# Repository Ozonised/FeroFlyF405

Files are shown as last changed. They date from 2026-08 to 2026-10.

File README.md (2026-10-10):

# FeroFlyF405
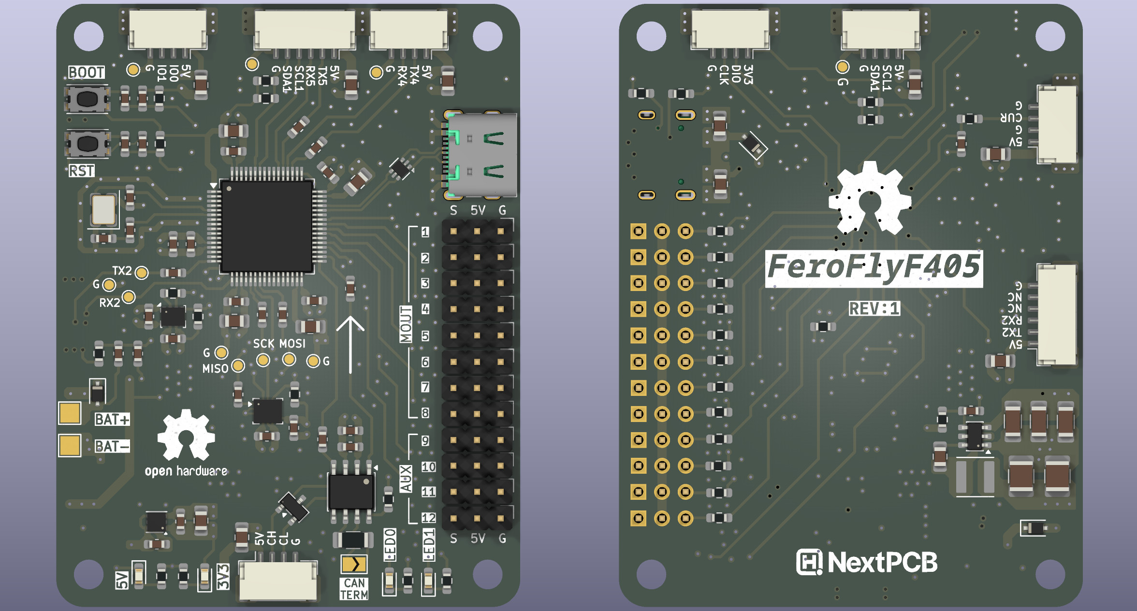
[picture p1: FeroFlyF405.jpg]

FeroFlyF405 is an opensource flight controller based on STM32F405 and runs the open source flight controller firmware, [INAV](https://github.com/iNavFlight/inav).

FeroFlyF405 is designed to be an open hardware platform that enthusiasts and developers can study, modify, build, and use in their own projects.

For those interested in the design process, watch the [YouTube](https://youtu.be/mWAzVRxgooY) video.

## Features

* **Microcontroller:** STM32F405
* **IMU:** LSM6DSL 6-axis accelerometer and gyroscope
* **Barometer:** DPS368
* **Firmware:** INAV
* **Motor outputs:** 12 timer-based output channels
* **CAN bus:** For compatible peripherals
* **I2C:** External sensor and peripheral connectivity
* **UARTs:** 3 serial ports
* **PINIO:** 2 programmable GPIO outputs
* **Current sensing:** Dedicated input for an external current sensor

## Sponsor

A special thanks to **[NextPCB](https://www.nextpcb.com/?code=ozonised)** for sponsoring the FeroFlyF405 project and supporting the development of this open-source flight controller.

Their support helped bring the custom PCB design from the screen to the physical board.

Thank you, NextPCB, for supporting open-source hardware development!

Get high quality PCBs for your project at an affordable rate from **[NextPCB](https://www.nextpcb.com/)**.

## Connectivity

| Interface | Quantity | Purpose |
| --- | ---: | --- |
| Motor outputs  | 12 | ESCs and other compatible timer-based outputs |
| CAN bus | 1 | Compatible CAN peripherals |
| I2C | 1 | External sensors and peripherals |
| UART | 3 | Receivers, GPS, telemetry, and other serial devices |
| PINIO | 2 | User-configurable GPIO outputs |
| Current sensor | 1 | External current-sensing module |

> **Note:** Motor output capabilities depend on timer allocation, DMA availability, and firmware configuration. Not all outputs necessarily support every ESC protocol.

## Connectors and Pinout

FeroFlyF405 follows the **Pixhawk connector and pinout standard** for its applicable peripheral interfaces and uses **JST-GH series connectors**.

The PINIO and current-sensor connectors are exceptions to this convention.

## Firmware

FeroFlyF405 runs [INAV](https://github.com/iNavFlight/inav), an open-source flight control firmware for multirotor, fixed-wing, and other UAV platforms.

FeroFlyF405 uses a board-specific INAV target to configure its MCU pins, sensors, timers, communication interfaces, and other hardware resources.

Useful links:
* [FeroFlyF405 Target & Binary](https://github.com/Ozonised/FeroFlyF405-INAV-files)
* [INAV source code](https://github.com/iNavFlight/inav)
* [INAV documentation](https://inavflight.github.io/)

## 3D-Printed Enclosure

The FeroFlyF405 enclosure consists of three 3D-printable parts:

* **Enclosure Top** (`FeroFlyF405 Enclosure-Top.stl`) — Upper section of the enclosure.
* **Enclosure Bottom** (`FeroFlyF405 Enclosure-Bottom.stl`) — Lower section of the enclosure.
* **LED Cap** (`FeroFlyF405 Enclosure-Led Cap.stl`) — Cover for the status and power LEDs, designed to be printed using translucent filament to allow the LED light to pass through.

### Printing Recommendations

* **Top and Bottom:** PETG filament is recommended for durability and heat resistance.
* **LED Cap:** Use translucent filament for better LED visibility.
* **Fasteners:** The enclosure uses M3 screws and threaded inserts.

The STL files are provided so you can print and assemble the enclosure yourself.

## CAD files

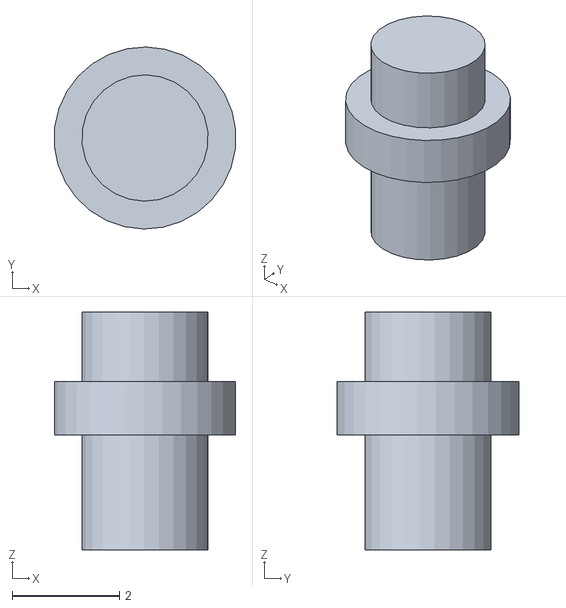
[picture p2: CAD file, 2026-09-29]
Enclosure/FeroFlyF405 Enclosure-Led Cap.stl
3.39 x 3.40 x 4.45

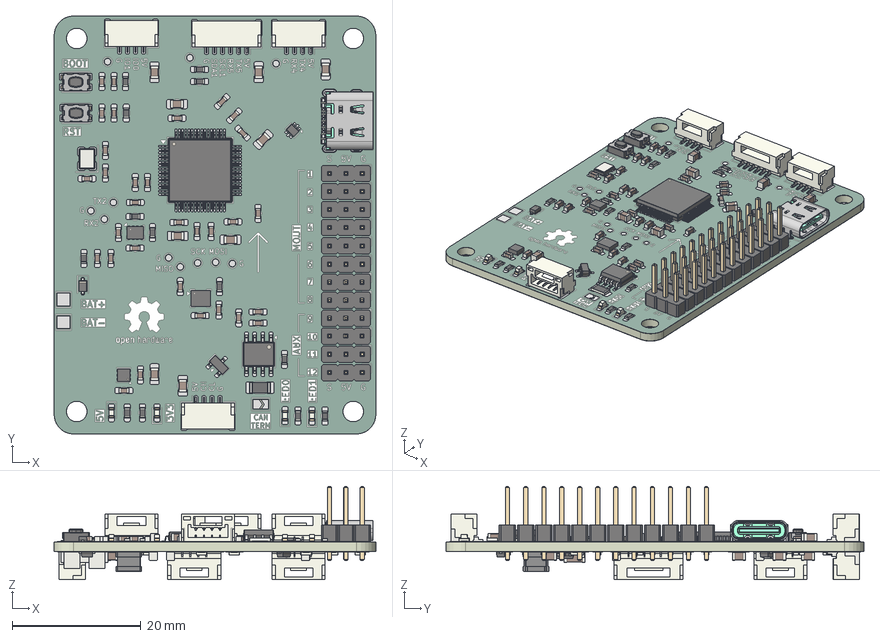
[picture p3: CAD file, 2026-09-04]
FeroFlyF405.step
50.0 x 65.0 x 14.5 mm
LED_0603_1608Metric x 4
R_0603_1608Metric x 34
SOT_666
Bosch_LGA_8_2x25mm_P065mm_ClockwisePinNumbering
C_0603_1608Metric x 33
PinHeader_1x03_P254mm_Vertical x 12
JST_SM04B_GHS_TB x 6
_X2_4E006B21_X0_MOLDING_-261340
WSON_6_1EP_2x2mm_P065mm_EP1x16mm
SOIC-8_3.9x4.9mm_P1.27mm
C_0805_2012Metric x 15
LQFP-64_10x10mm_P0.5mm
SW_Push_1P1T_NO_CK_KMR2 x 2
JST_SM06B_GHS_TB x 2
LGA_14_3x25mm_P05mm_LayoutBorder3x4y
SOT-23
D_SOD_323F x 3
Crystal_SMD_3225-4Pin_3.2x2.5mm
R_1206_3216Metric
C_1206_3216Metric x 3
TSOT-23-6
C_1210_3225Metric x 2
ASPI-4030S
FeroFlyF405_pad
FeroFlyF405_silkscreen x 2
FeroFlyF405_soldermask x 2
FeroFlyF405_PCB

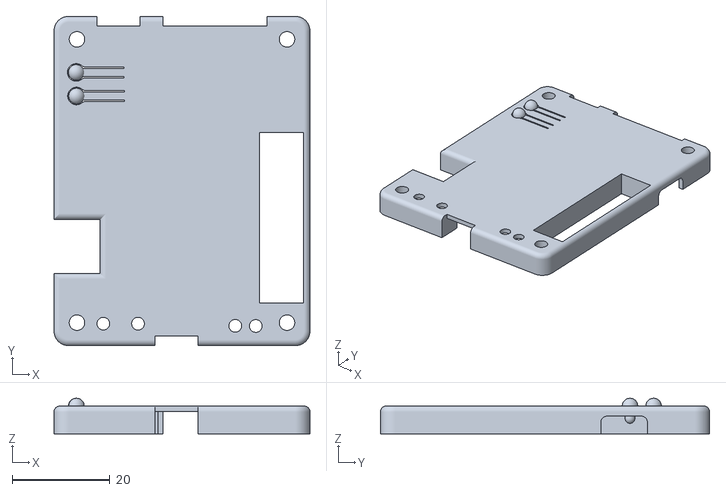
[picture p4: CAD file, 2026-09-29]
Enclosure/FeroFlyF405 Enclosure-Top.stl
52.4 x 67.4 x 7.28

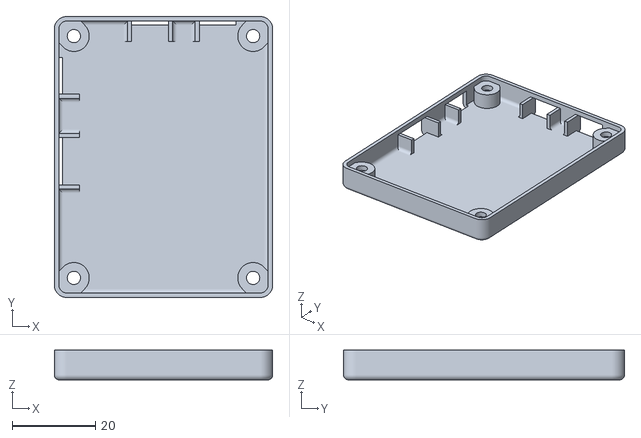
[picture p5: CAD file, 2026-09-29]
Enclosure/FeroFlyF405 Enclosure-Bottom.stl
52.4 x 67.4 x 7.14

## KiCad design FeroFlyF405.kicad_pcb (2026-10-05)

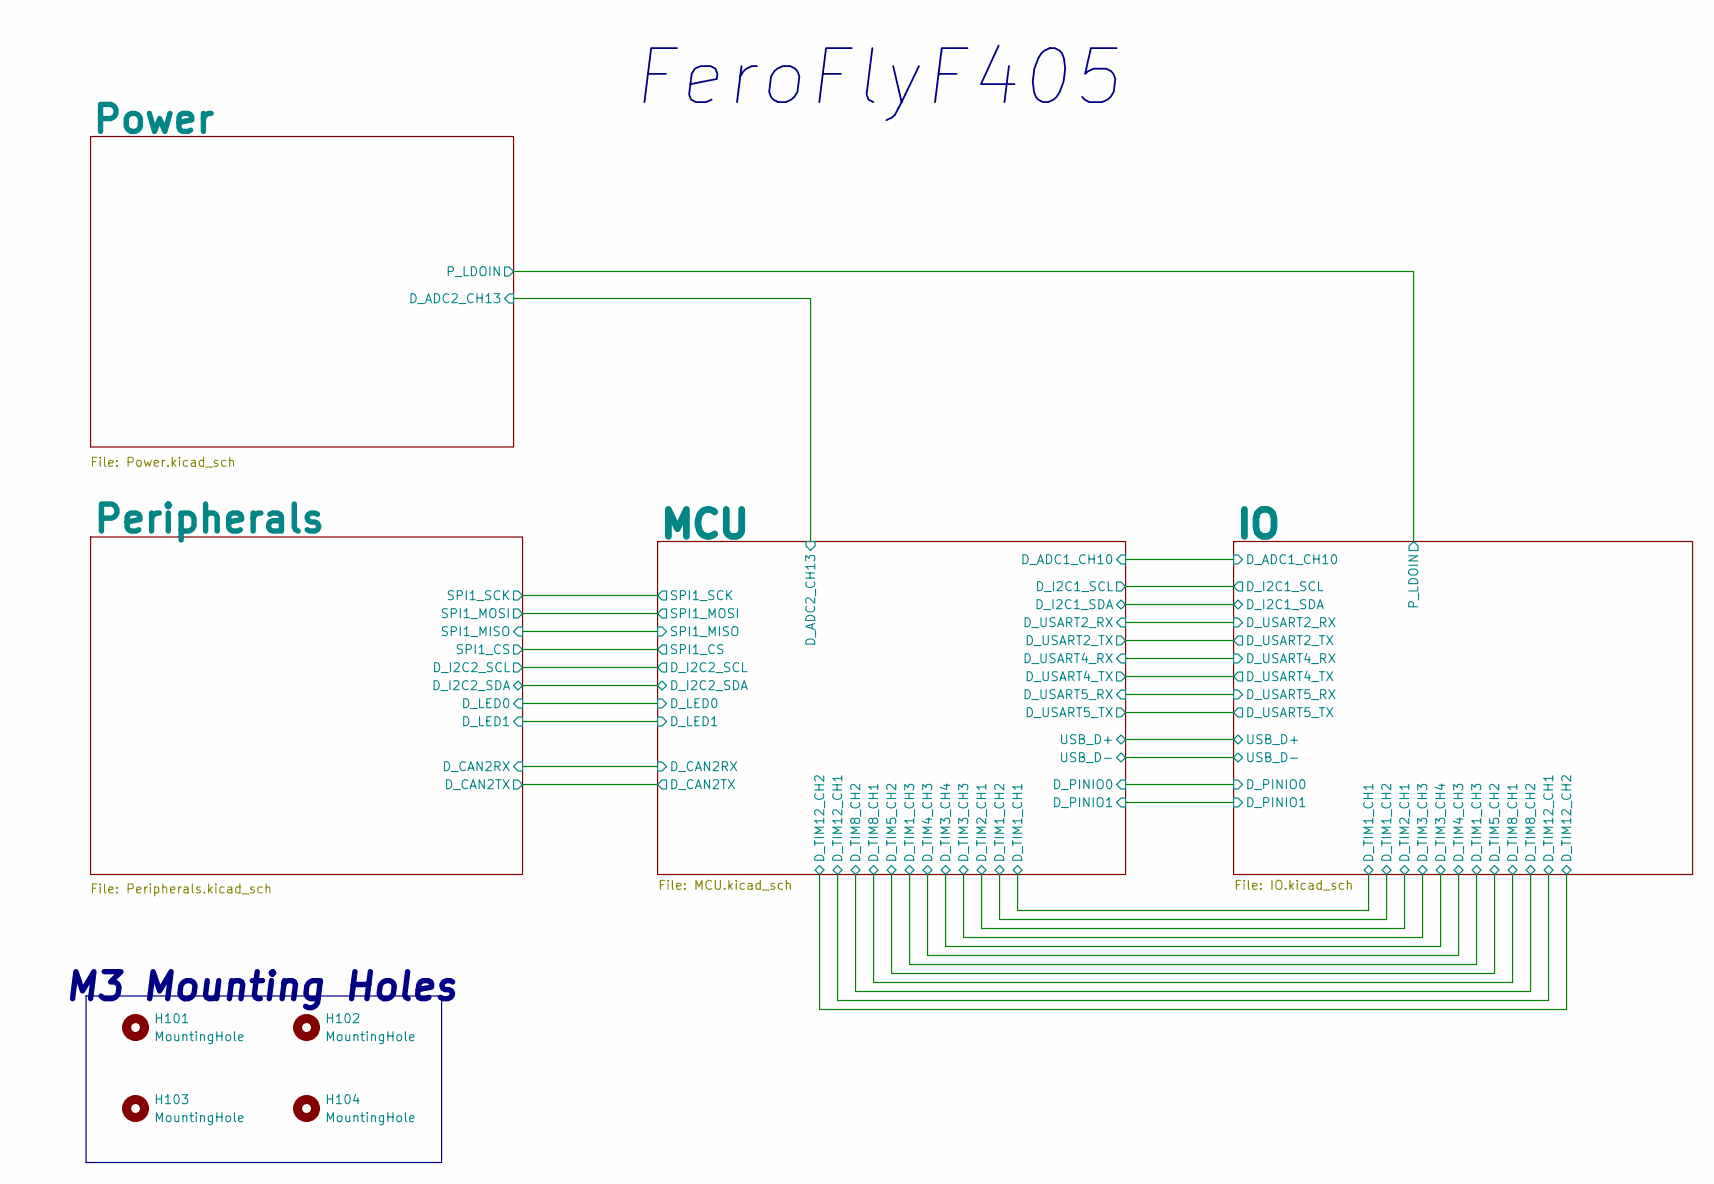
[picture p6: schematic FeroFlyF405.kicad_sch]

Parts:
H101, H102, H103, H104: MountingHole; MountingHole_3.2mm_M3

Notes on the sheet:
M3 Mounting Holes
FeroFlyF405

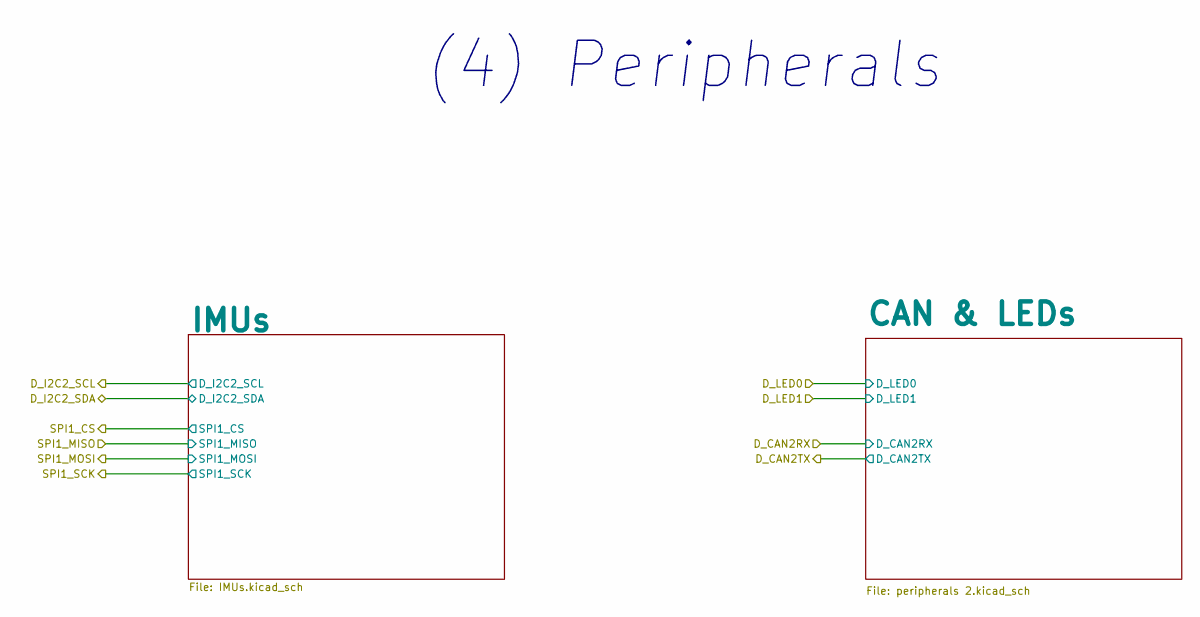
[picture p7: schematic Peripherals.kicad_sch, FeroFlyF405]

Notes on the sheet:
(4) Peripherals

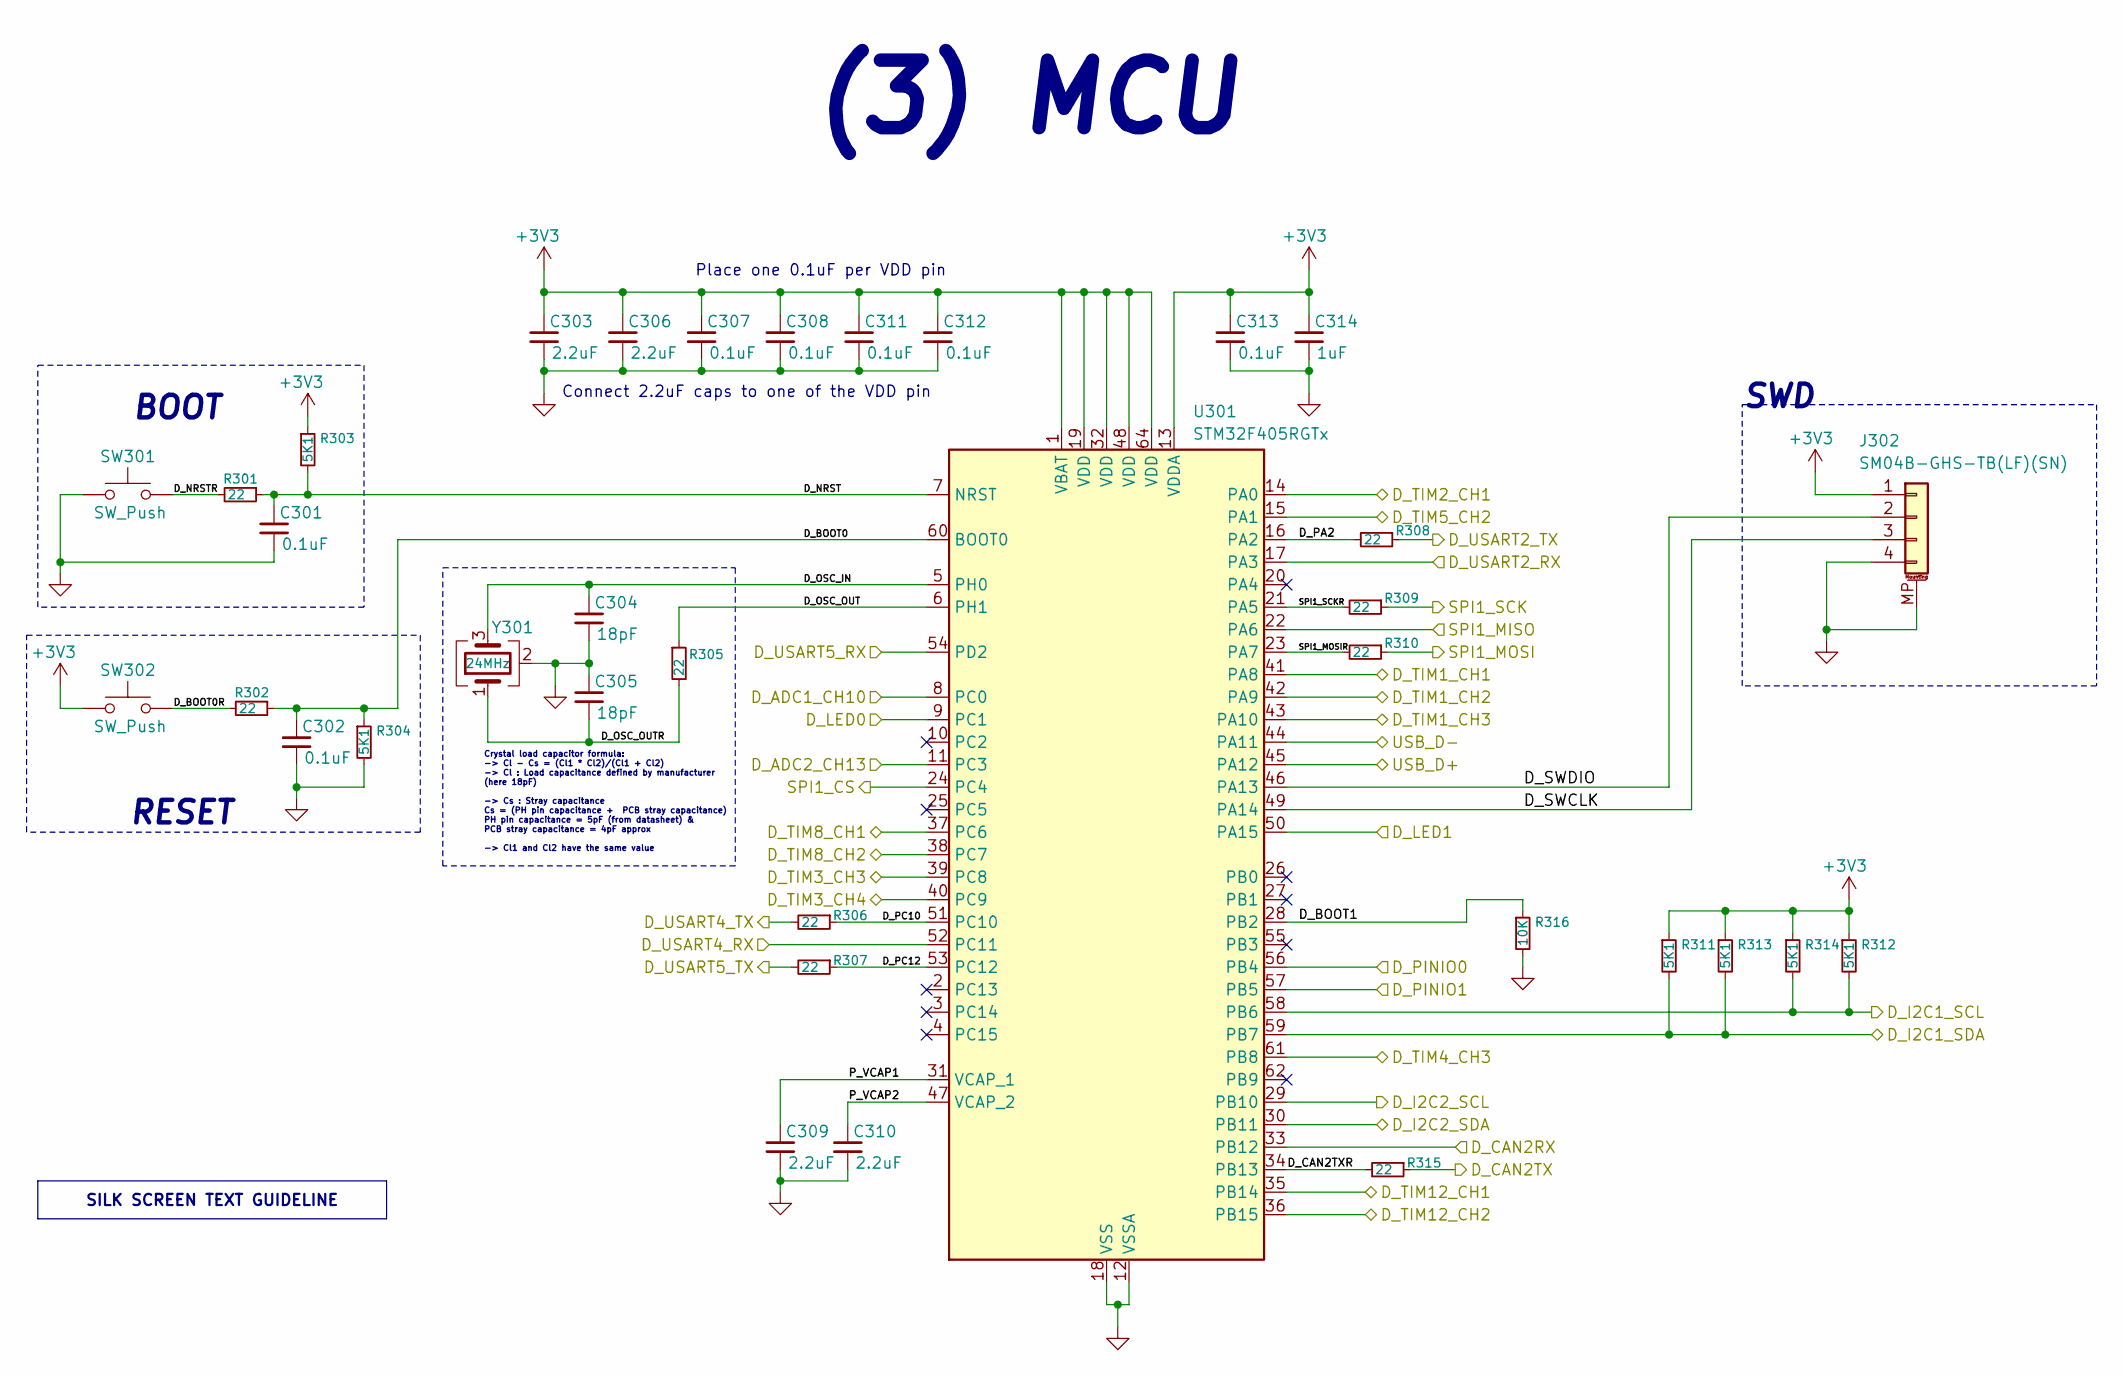
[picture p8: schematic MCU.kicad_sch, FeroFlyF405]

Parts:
C301, C302, C307, C308, C311, C312, C313: 0.1uF; C_0603_1608Metric_Pad1.08x0.95mm_HandSolder; MPN C1608X5R1H104K080AA
C303, C306, C309, C310: 2.2uF; C_0805_2012Metric_Pad1.18x1.45mm_HandSolder; MPN GCM21BR71C225KA64L
C304, C305: 18pF; C_0603_1608Metric_Pad1.08x0.95mm_HandSolder; MPN 06035A180JAT4A
C314: 1uF; C_0603_1608Metric_Pad1.08x0.95mm_HandSolder; MPN C1608X7R1V105K080AC
J302: SM04B-GHS-TB(LF)(SN); JST_GH_SM04B-GHS-TB_1x04-1MP_P1.25mm_Horizontal; MPN SM04B-GHS-TB(LF)(SN)
R301, R302, R305, R306, R307, R308, R309, R310, R315: 22; C_0603_1608Metric_Pad1.08x0.95mm_HandSolder; MPN CR0603-FX-22R0ELF
R303, R304, R311, R312, R313, R314: 5K1; R_0603_1608Metric_Pad0.98x0.95mm_HandSolder; MPN CR0603-FX-5101ELF
R316: 10K; R_0603_1608Metric_Pad0.98x0.95mm_HandSolder; MPN CR0603-FX-1002ELF
SW301, SW302: SW_Push; SW_Push_1P1T_NO_CK_KMR2; MPN RKB2SJM250SMTR LFS
U301: STM32F405RGTx; LQFP-64_10x10mm_P0.5mm; MPN STM32F405RGT6
Y301: 24MHz; Crystal_SMD_3225-4Pin_3.2x2.5mm; MPN ABM8-24.000MHZ-D4Y-T

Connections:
+3V3: C303.1, C306.1, C307.1, C308.1, C311.1, C312.1, C313.1, C314.1, J302.1, R303.1, R311.1, R312.1, R313.1, R314.1, SW302.1, U301.1 (VBAT), U301.13 (VDDA), U301.19 (VDD), U301.32 (VDD), U301.48 (VDD), U301.64 (VDD); also elsewhere on the board
/IO/D_ADC1_CH10: U301.8 (PC0); also elsewhere on the board
/IO/D_I2C1_SCL: R312.2, R314.2, U301.58 (PB6); also elsewhere on the board
/IO/D_I2C1_SDA: R311.2, R313.2, U301.59 (PB7); also elsewhere on the board
/IO/D_PINIO0: U301.56 (PB4); also elsewhere on the board
/IO/D_PINIO1: U301.57 (PB5); also elsewhere on the board
/IO/D_TIM1_CH1: U301.41 (PA8); also elsewhere on the board
/IO/D_TIM1_CH2: U301.42 (PA9); also elsewhere on the board
/IO/D_TIM1_CH3: U301.43 (PA10); also elsewhere on the board
/IO/D_TIM2_CH1: U301.14 (PA0); also elsewhere on the board
/IO/D_TIM3_CH3: U301.39 (PC8); also elsewhere on the board
/IO/D_TIM3_CH4: U301.40 (PC9); also elsewhere on the board
/IO/D_TIM4_CH3: U301.61 (PB8); also elsewhere on the board
/IO/D_TIM5_CH2: U301.15 (PA1); also elsewhere on the board
/IO/D_TIM8_CH1: U301.37 (PC6); also elsewhere on the board
/IO/D_TIM8_CH2: U301.38 (PC7); also elsewhere on the board
/IO/D_TIM12_CH1: U301.35 (PB14); also elsewhere on the board
/IO/D_TIM12_CH2: U301.36 (PB15); also elsewhere on the board
/IO/D_USART2_RX: U301.17 (PA3); also elsewhere on the board
/IO/D_USART2_TX: R308.1; also elsewhere on the board
/IO/D_USART4_RX: U301.52 (PC11); also elsewhere on the board
/IO/D_USART4_TX: R306.2; also elsewhere on the board
/IO/D_USART5_RX: U301.54 (PD2); also elsewhere on the board
/IO/D_USART5_TX: R307.2; also elsewhere on the board
/IO/USB_D+: U301.45 (PA12); also elsewhere on the board
/IO/USB_D-: U301.44 (PA11); also elsewhere on the board
/MCU/D_ADC2_CH13: U301.11 (PC3); also elsewhere on the board
/MCU/D_BOOT0: C302.1, R302.1, R304.1, U301.60 (BOOT0)
/MCU/D_BOOT0R: R302.2, SW302.2
/MCU/D_BOOT1: R316.1, U301.28 (PB2)
/MCU/D_CAN2RX: U301.33 (PB12); also elsewhere on the board
/MCU/D_CAN2TX: R315.1; also elsewhere on the board
/MCU/D_CAN2TXR: R315.2, U301.34 (PB13)
/MCU/D_I2C2_SCL: U301.29 (PB10); also elsewhere on the board
/MCU/D_I2C2_SDA: U301.30 (PB11); also elsewhere on the board
/MCU/D_LED0: U301.9 (PC1); also elsewhere on the board
/MCU/D_LED1: U301.50 (PA15); also elsewhere on the board
/MCU/D_NRST: C301.1, R301.1, R303.2, U301.7 (NRST)
/MCU/D_NRSTR: R301.2, SW301.2
/MCU/D_OSC_IN: C304.1, U301.5 (PH0), Y301.3
/MCU/D_OSC_OUT: R305.1, U301.6 (PH1)
/MCU/D_OSC_OUTR: C305.2, R305.2, Y301.1
/MCU/D_PA2: R308.2, U301.16 (PA2)
/MCU/D_PC10: R306.1, U301.51 (PC10)
/MCU/D_PC12: R307.1, U301.53 (PC12)
/MCU/D_SWCLK: J302.3, U301.49 (PA14)
/MCU/D_SWDIO: J302.2, U301.46 (PA13)
/MCU/P_VCAP1: C309.1, U301.31 (VCAP_1)
/MCU/P_VCAP2: C310.1, U301.47 (VCAP_2)
/MCU/SPI1_CS: U301.24 (PC4); also elsewhere on the board
/MCU/SPI1_MISO: U301.22 (PA6); also elsewhere on the board
/MCU/SPI1_MOSI: R310.1; also elsewhere on the board
/MCU/SPI1_MOSIR: R310.2, U301.23 (PA7)
/MCU/SPI1_SCK: R309.1; also elsewhere on the board
/MCU/SPI1_SCKR: R309.2, U301.21 (PA5)
GND: C301.2, C302.2, C303.2, C304.2, C305.1, C306.2, C307.2, C308.2, C309.2, C310.2, C311.2, C312.2, C313.2, C314.2, J302.4, J302.MP (MountPin), R304.2, R316.2, SW301.1, U301.12 (VSSA), U301.18 (VSS), U301.63 (VSS), Y301.2 (G), Y301.4 (G); also elsewhere on the board

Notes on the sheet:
RESET
SWD
Place one 0.1uF per VDD pin
Crystal load capacitor formula: -> Cl - Cs = (Cl1 * Cl2)/(Cl1 + Cl2) -> Cl : Load capacitance defined by manufacturer (here 18pF) -> Cs : Stray capacitance Cs = (PH pin capacitance + PCB stray capacitance) PH pin capacitance = 5pF (from datasheet) & PCB stray capacitance = 4pF approx -> Cl1 and Cl2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
(3) MCU
Connect 2.2uF caps to one of the VDD pin
BOOT
SILK SCREEN TEXT GUIDELINE

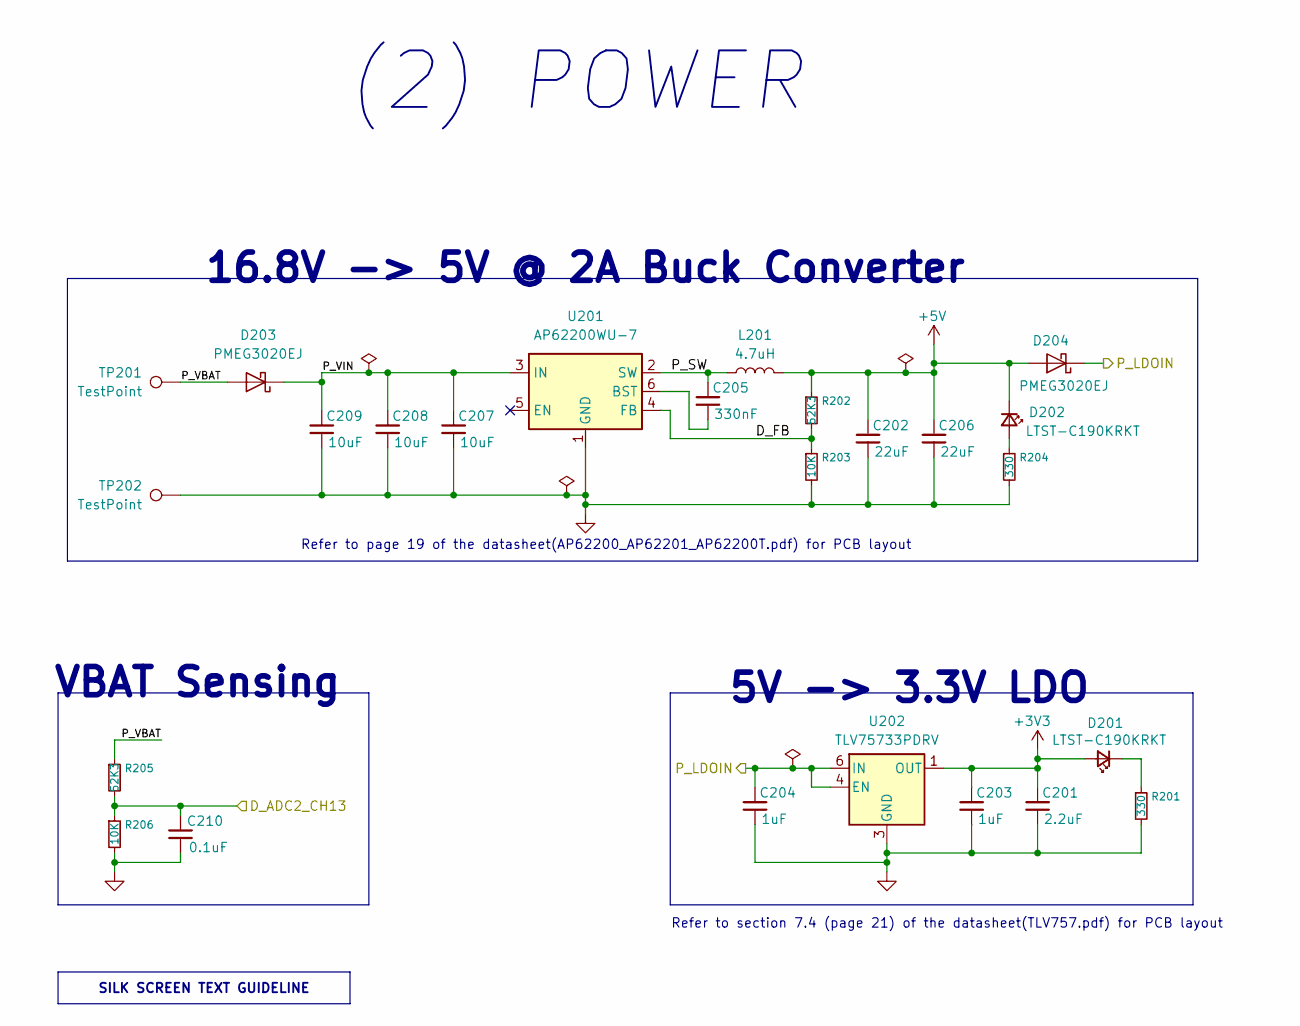
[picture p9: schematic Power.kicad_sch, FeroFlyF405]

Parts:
C201: 2.2uF; C_0805_2012Metric_Pad1.18x1.45mm_HandSolder; MPN GCM21BR71C225KA64L
C202, C206: 22uF; C_1210_3225Metric_Pad1.33x2.70mm_HandSolder; MPN C3225X5R1C226M250AA
C203, C204: 1uF; C_0603_1608Metric_Pad1.08x0.95mm_HandSolder; MPN C1608X7R1V105K080AC
C205: 330nF; C_0805_2012Metric_Pad1.18x1.45mm_HandSolder; MPN CGA4J2X7R1H334K125AA
C207, C208, C209: 10uF; C_1206_3216Metric_Pad1.33x1.80mm_HandSolder; MPN C3216X5R1E106K160AB
C210: 0.1uF; C_0603_1608Metric_Pad1.08x0.95mm_HandSolder; MPN C1608X5R1H104K080AA
D201, D202: LTST-C190KRKT; LED_0603_1608Metric_Pad1.05x0.95mm_HandSolder; MPN LTST-C190KRKT
D203, D204: PMEG3020EJ; D_SOD-323F; MPN PMEG3020EJ,115
L201: 4.7uH; L_Abracon_ASPI-4030S; MPN ASPI-4030S-4R7M-T
R201, R204: 330; R_0603_1608Metric_Pad0.98x0.95mm_HandSolder; MPN CR0603-FX-3300ELF
R202, R205: 52K3; C_0603_1608Metric_Pad1.08x0.95mm_HandSolder; MPN CR0603-FX-5232ELF
R203, R206: 10K; R_0603_1608Metric_Pad0.98x0.95mm_HandSolder; MPN CR0603-FX-1002ELF
TP201, TP202: TestPoint; TestPoint_Pad_2.0x2.0mm
U201: AP62200WU-7; TSOT-23-6; MPN AP62200WU-7
U202: TLV75733PDRV; WSON-6-1EP_2x2mm_P0.65mm_EP1x1.6mm; MPN TLV75733PDRVR

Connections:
+3V3: C201.1, C203.1, D201.2 (A), U202.1 (OUT); also elsewhere on the board
+5V: C202.1, C206.1, D202.1 (K), D204.2 (A), L201.2, R202.1; also elsewhere on the board
/IO/P_LDOIN: C204.1, D204.1 (K), U202.4 (EN), U202.6 (IN); also elsewhere on the board
/MCU/D_ADC2_CH13: C210.1, R205.2, R206.1; also elsewhere on the board
/Power/D_FB: R202.2, R203.1, U201.4 (FB)
/Power/P_SW: C205.1, L201.1, U201.2 (SW)
/Power/P_VBAT: D203.2 (A), R205.1, TP201.1 (1_1)
/Power/P_VIN: C207.1, C208.1, C209.1, D203.1 (K), U201.3 (IN)
GND: C201.2, C202.2, C203.2, C204.2, C206.2, C207.2, C208.2, C209.2, C210.2, R201.2, R203.2, R204.2, R206.2, TP202.1 (1_1), U201.1 (GND), U202.3 (GND), U202.7 (GND); also elsewhere on the board
unnamed: D201.1 (K), R201.1
unnamed: D202.2 (A), R204.1
unnamed: C205.2, U201.6 (BST)

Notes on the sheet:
Refer to page 19 of the datasheet(AP62200_AP62201_AP62200T.pdf) for PCB layout
5V -> 3.3V LDO
16.8V -> 5V @ 2A Buck Converter
(2) POWER
Refer to section 7.4 (page 21) of the datasheet(TLV757.pdf) for PCB layout
VBAT Sensing
SILK SCREEN TEXT GUIDELINE

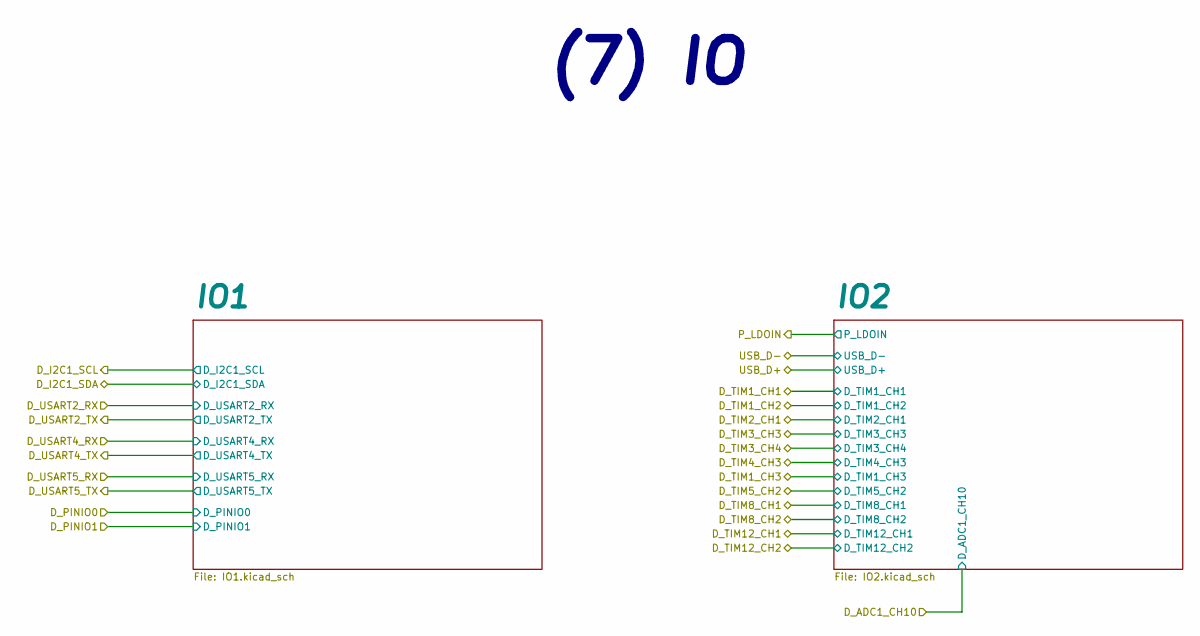
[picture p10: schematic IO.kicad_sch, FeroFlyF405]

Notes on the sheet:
(7) IO

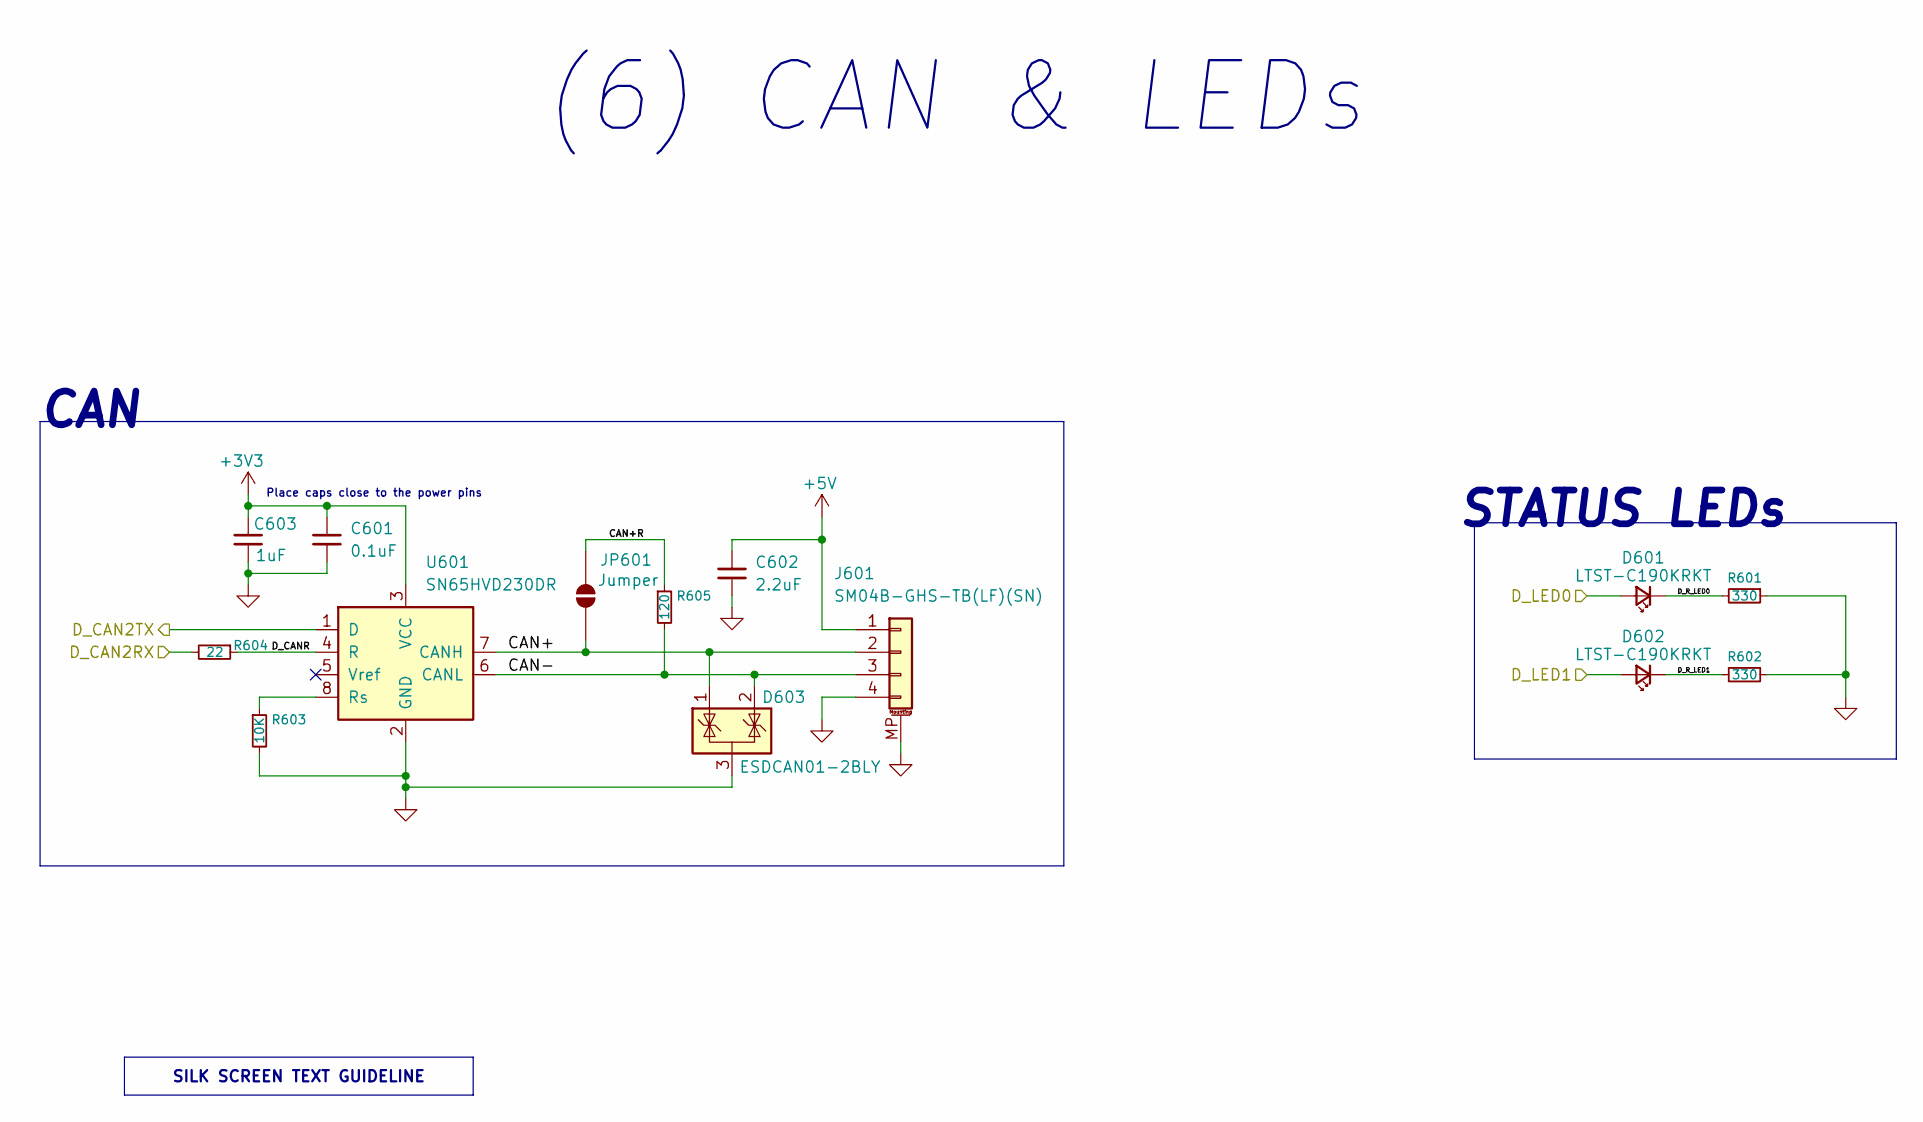
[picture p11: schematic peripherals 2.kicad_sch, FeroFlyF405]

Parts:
C601: 0.1uF; C_0603_1608Metric_Pad1.08x0.95mm_HandSolder; MPN C1608X5R1H104K080AA
C602: 2.2uF; C_0805_2012Metric_Pad1.18x1.45mm_HandSolder; MPN GCM21BR71C225KA64L
C603: 1uF; C_0603_1608Metric_Pad1.08x0.95mm_HandSolder; MPN C1608X7R1V105K080AC
D601, D602: LTST-C190KRKT; LED_0603_1608Metric_Pad1.05x0.95mm_HandSolder; MPN LTST-C190KRKT
D603: ESDCAN01-2BLY; SOT-23; MPN ESDCAN01-2BLY
J601: SM04B-GHS-TB(LF)(SN); JST_GH_SM04B-GHS-TB_1x04-1MP_P1.25mm_Horizontal; MPN SM04B-GHS-TB(LF)(SN)
JP601: Jumper; SolderJumper-2_P1.3mm_Open_TrianglePad1.0x1.5mm
R601, R602: 330; R_0603_1608Metric_Pad0.98x0.95mm_HandSolder; MPN CR0603-FX-3300ELF
R603: 10K; R_0603_1608Metric_Pad0.98x0.95mm_HandSolder; MPN CR0603-FX-1002ELF
R604: 22; C_0603_1608Metric_Pad1.08x0.95mm_HandSolder; MPN CR0603-FX-22R0ELF
R605: 120; R_1206_3216Metric_Pad1.30x1.75mm_HandSolder; MPN CR1206-FX-1200ELF
U601: SN65HVD230DR; SOIC-8_3.9x4.9mm_P1.27mm; MPN SN65HVD230DR

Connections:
+3V3: C601.1, C603.1, U601.3 (VCC); also elsewhere on the board
+5V: C602.1, J601.1; also elsewhere on the board
/MCU/D_CAN2RX: R604.2; also elsewhere on the board
/MCU/D_CAN2TX: U601.1 (D); also elsewhere on the board
/MCU/D_LED0: D601.2 (A); also elsewhere on the board
/MCU/D_LED1: D602.2 (A); also elsewhere on the board
/Peripherals/CAN & LEDs/CAN+: D603.1 (K), J601.2, JP601.1 (A), U601.7 (CANH)
/Peripherals/CAN & LEDs/CAN+R: JP601.2 (B), R605.1
/Peripherals/CAN & LEDs/CAN-: D603.2 (K), J601.3, R605.2, U601.6 (CANL)
/Peripherals/CAN & LEDs/D_CANR: R604.1, U601.4 (R)
/Peripherals/CAN & LEDs/D_R_LED0: D601.1 (K), R601.2
/Peripherals/CAN & LEDs/D_R_LED1: D602.1 (K), R602.2
GND: C601.2, C602.2, C603.2, D603.3 (A), J601.4, J601.MP (MountPin), R601.1, R602.1, R603.2, U601.2 (GND); also elsewhere on the board
unnamed: R603.1, U601.8 (Rs)

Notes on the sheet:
(6) CAN & LEDs
STATUS LEDs
Place caps close to the power pins
CAN
SILK SCREEN TEXT GUIDELINE

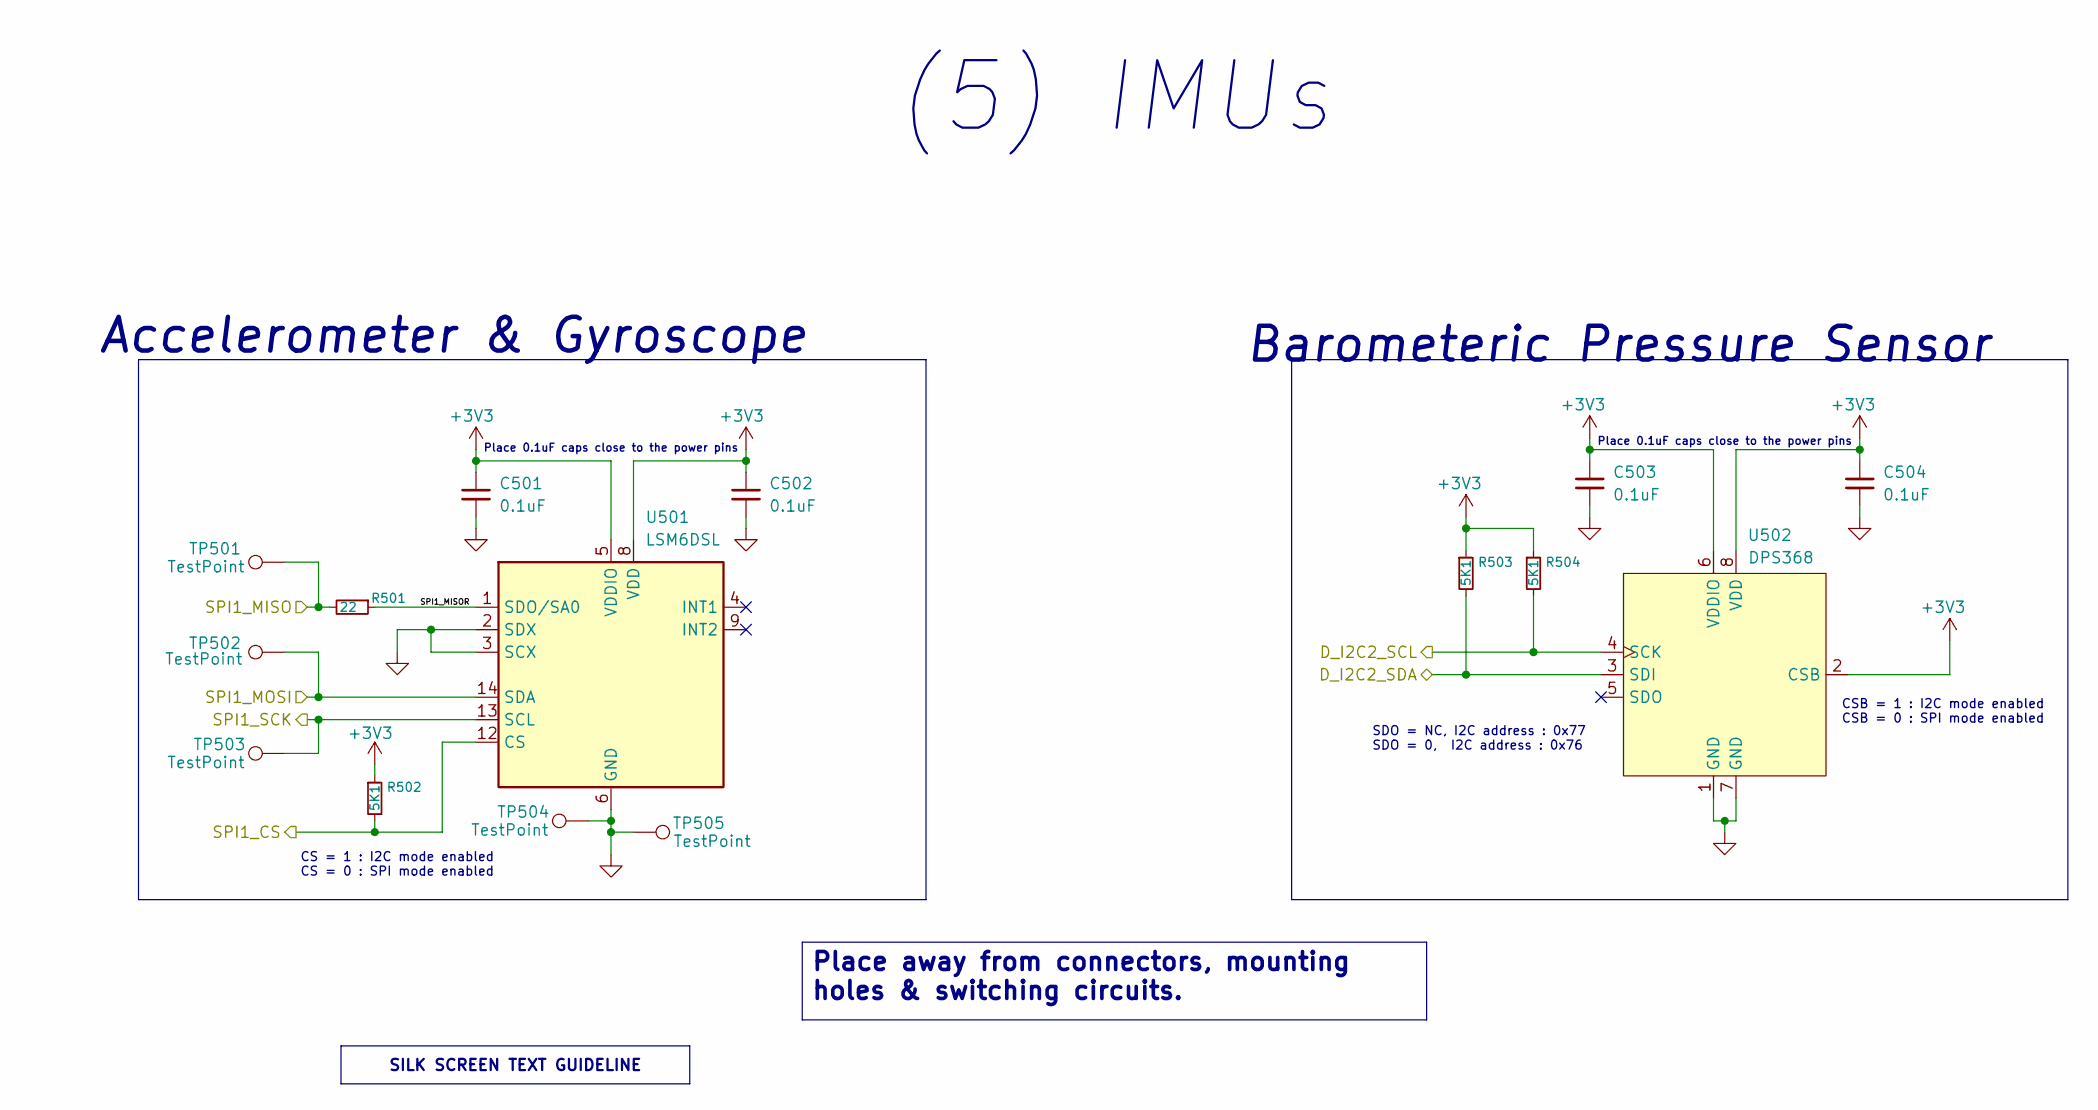
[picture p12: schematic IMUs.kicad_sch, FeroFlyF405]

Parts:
C501, C502, C503, C504: 0.1uF; C_0603_1608Metric_Pad1.08x0.95mm_HandSolder; MPN C1608X5R1H104K080AA
R501: 22; C_0603_1608Metric_Pad1.08x0.95mm_HandSolder; MPN CR0603-FX-22R0ELF
R502, R503, R504: 5K1; R_0603_1608Metric_Pad0.98x0.95mm_HandSolder; MPN CR0603-FX-5101ELF
TP501, TP502, TP503, TP504, TP505: TestPoint; TestPoint_Pad_D1.0mm
U501: LSM6DSL; LGA-14_3x2.5mm_P0.5mm_LayoutBorder3x4y; MPN LSM6DSL
U502: DPS368; Bosch_LGA-8_2x2.5mm_P0.65mm_ClockwisePinNumbering

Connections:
+3V3: C501.1, C502.1, C503.1, C504.1, R502.1, R503.1, R504.1, U501.5 (VDDIO), U501.8 (VDD), U502.2 (CSB), U502.6 (VDDIO), U502.8 (VDD); also elsewhere on the board
/MCU/D_I2C2_SCL: R504.2, U502.4 (SCK); also elsewhere on the board
/MCU/D_I2C2_SDA: R503.2, U502.3 (SDI); also elsewhere on the board
/MCU/SPI1_CS: R502.2, U501.12 (CS); also elsewhere on the board
/MCU/SPI1_MISO: R501.2, TP501.1 (1_1); also elsewhere on the board
/MCU/SPI1_MOSI: TP502.1 (1_1), U501.14 (SDA); also elsewhere on the board
/MCU/SPI1_SCK: TP503.1 (1_1), U501.13 (SCL); also elsewhere on the board
/Peripherals/IMUs/SPI1_MISOR: R501.1, U501.1 (SDO/SA0)
GND: C501.2, C502.2, C503.2, C504.2, TP504.1 (1_1), TP505.1 (1_1), U501.2 (SDX), U501.3 (SCX), U501.6 (GND), U501.7 (GND), U502.1 (GND), U502.7 (GND); also elsewhere on the board

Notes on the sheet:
SDO = NC, I2C address : 0x77 SDO = 0, I2C address : 0x76
CSB = 1 : I2C mode enabled CSB = 0 : SPI mode enabled
Accelerometer & Gyroscope
(5) IMUs
CS = 1 : I2C mode enabled CS = 0 : SPI mode enabled
Place 0.1uF caps close to the power pins
Barometeric Pressure Sensor
SILK SCREEN TEXT GUIDELINE
Place away from connectors, mounting holes & switching circuits.

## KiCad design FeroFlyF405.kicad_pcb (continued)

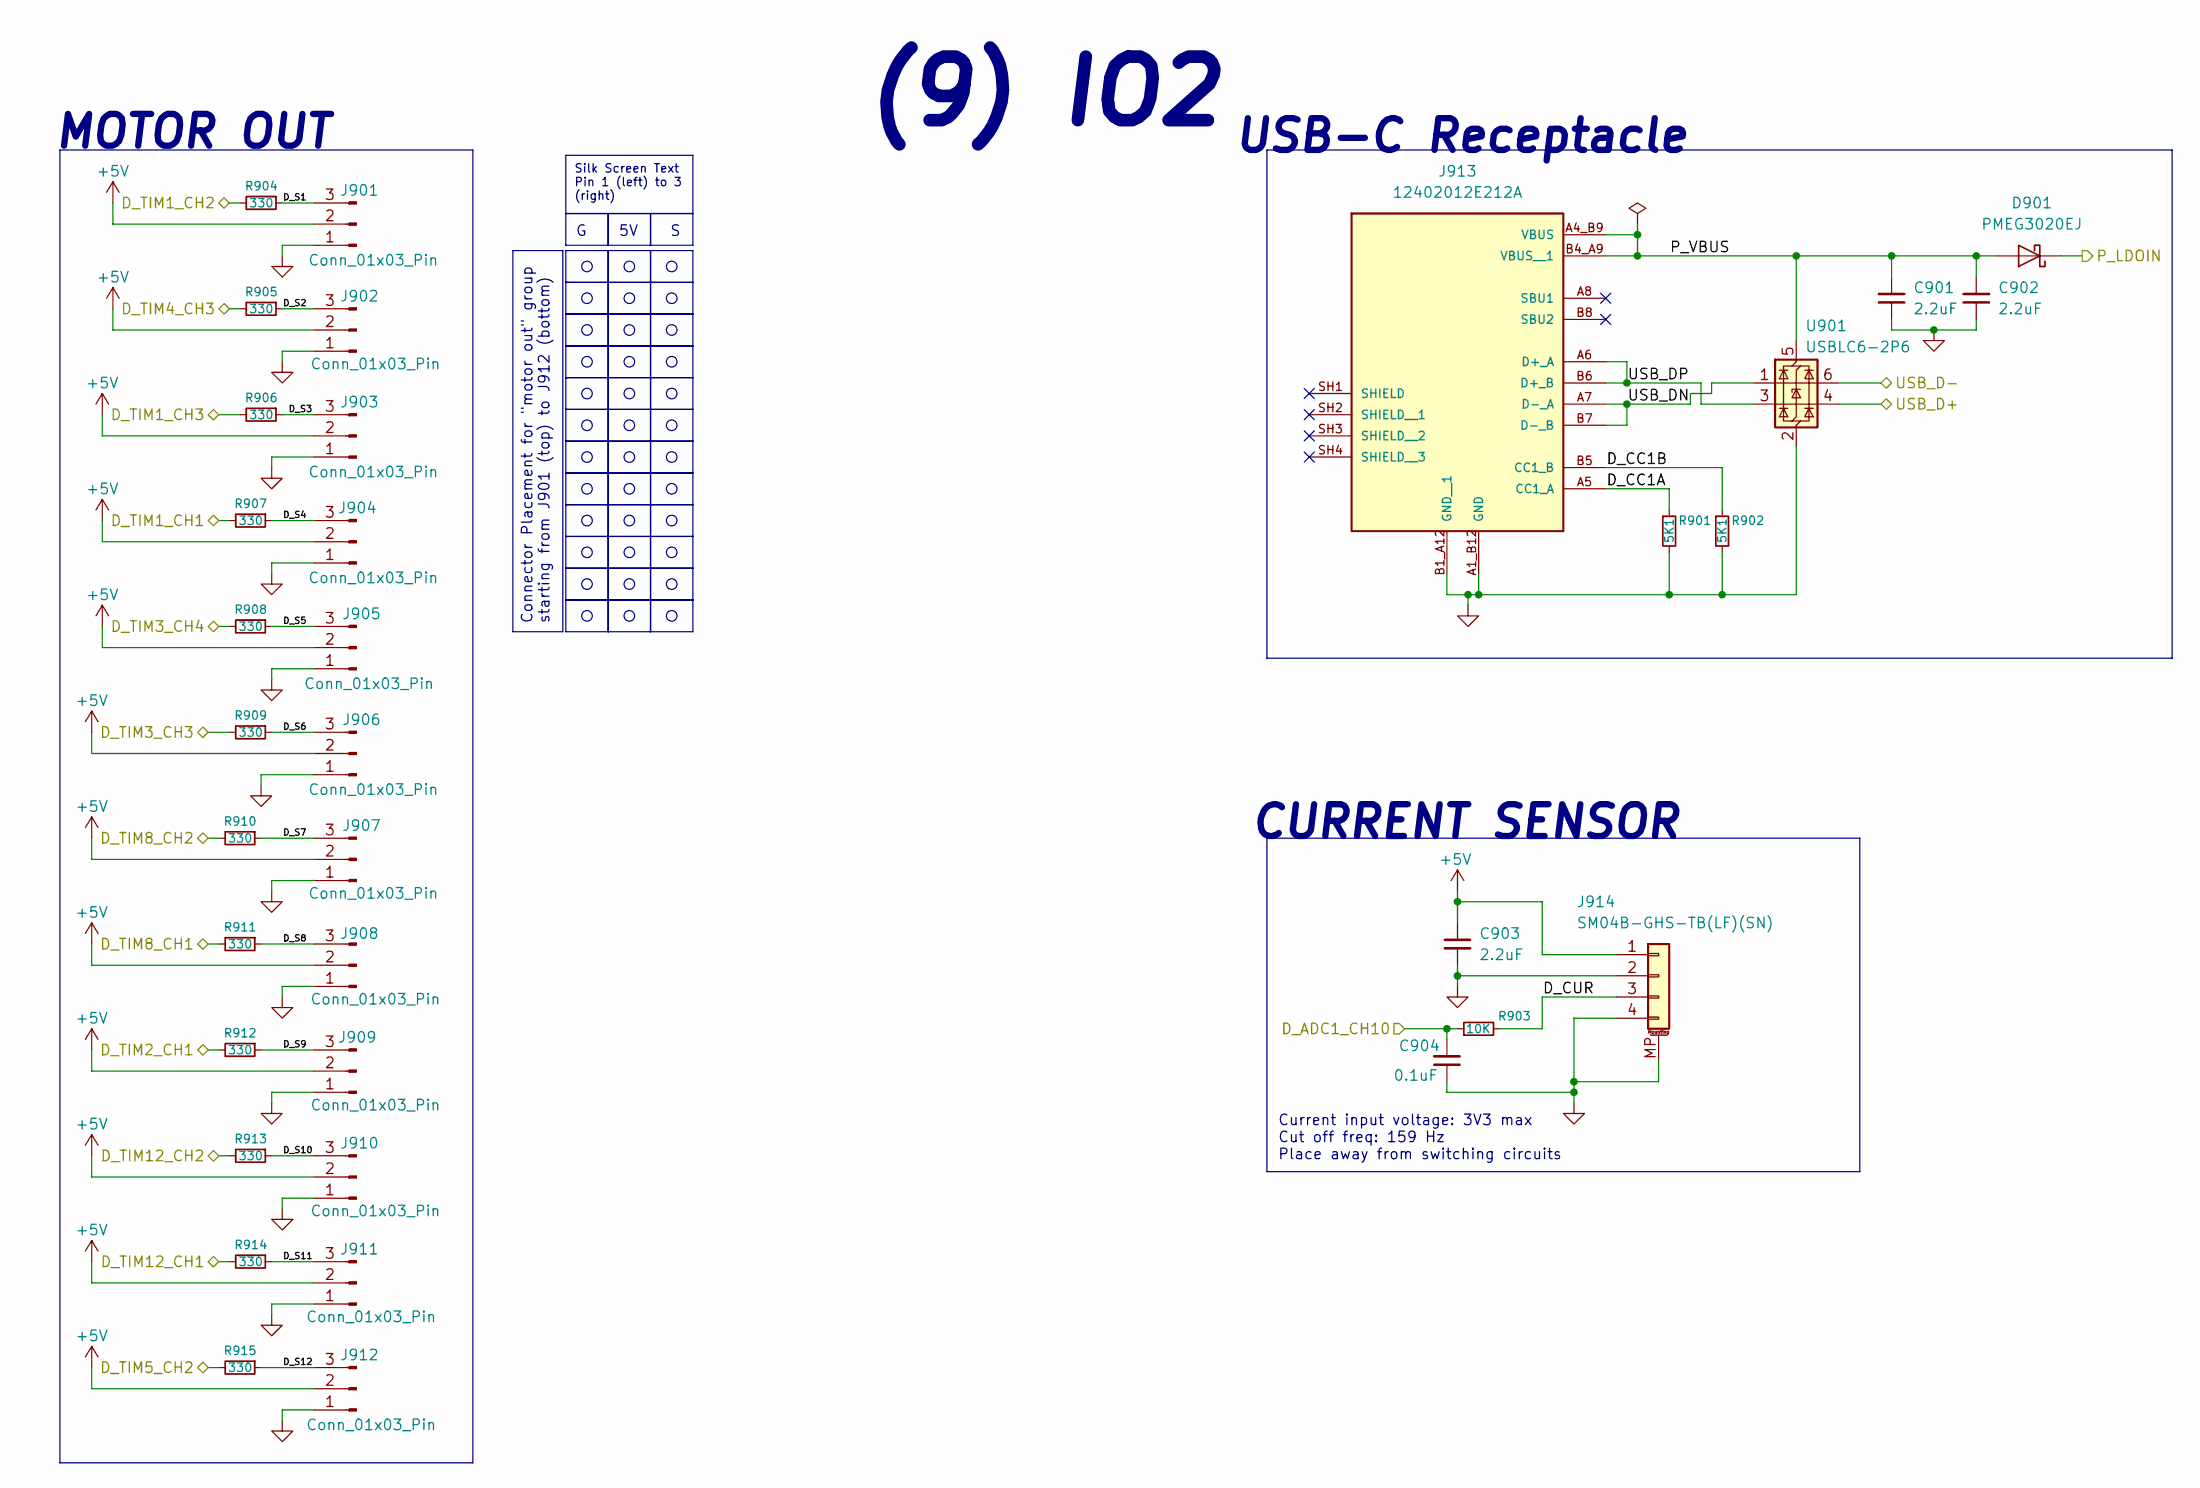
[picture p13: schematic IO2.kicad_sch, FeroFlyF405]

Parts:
C901, C902, C903: 2.2uF; C_0805_2012Metric_Pad1.18x1.45mm_HandSolder; MPN GCM21BR71C225KA64L
C904: 0.1uF; C_0603_1608Metric_Pad1.08x0.95mm_HandSolder; MPN C1608X5R1H104K080AA
D901: PMEG3020EJ; D_SOD-323F; MPN PMEG3020EJ,115
J901, J902, J903, J904, J905, J906, J907, J908, J909, J910, J911, J912: Conn_01x03_Pin; PinHeader_1x03_P2.54mm_Vertical
J913: 12402012E212A; AMPHENOL_12402012E212A; PARTREV 4
J914: SM04B-GHS-TB(LF)(SN); JST_GH_SM04B-GHS-TB_1x04-1MP_P1.25mm_Horizontal; MPN SM04B-GHS-TB(LF)(SN)
R901, R902: 5K1; R_0603_1608Metric_Pad0.98x0.95mm_HandSolder; MPN CR0603-FX-5101ELF
R903: 10K; R_0603_1608Metric_Pad0.98x0.95mm_HandSolder; MPN CR0603-FX-1002ELF
R904, R905, R906, R907, R908, R909, R910, R911, R912, R913, R914, R915: 330; R_0603_1608Metric_Pad0.98x0.95mm_HandSolder; MPN CR0603-FX-3300ELF
U901: USBLC6-2P6; SOT-666; MPN USBLC6-2P6

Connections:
+5V: C903.1, J901.2, J902.2, J903.2, J904.2, J905.2, J906.2, J907.2, J908.2, J909.2, J910.2, J911.2, J912.2, J914.1; also elsewhere on the board
/IO/D_ADC1_CH10: C904.1, R903.1; also elsewhere on the board
/IO/D_TIM1_CH1: R907.2; also elsewhere on the board
/IO/D_TIM1_CH2: R904.2; also elsewhere on the board
/IO/D_TIM1_CH3: R906.2; also elsewhere on the board
/IO/D_TIM2_CH1: R912.2; also elsewhere on the board
/IO/D_TIM3_CH3: R909.2; also elsewhere on the board
/IO/D_TIM3_CH4: R908.2; also elsewhere on the board
/IO/D_TIM4_CH3: R905.2; also elsewhere on the board
/IO/D_TIM5_CH2: R915.2; also elsewhere on the board
/IO/D_TIM8_CH1: R911.2; also elsewhere on the board
/IO/D_TIM8_CH2: R910.2; also elsewhere on the board
/IO/D_TIM12_CH1: R914.2; also elsewhere on the board
/IO/D_TIM12_CH2: R913.2; also elsewhere on the board
/IO/IO2/D_CC1A: J913.A5 (CC1_A), R901.1
/IO/IO2/D_CC1B: J913.B5 (CC1_B), R902.1
/IO/IO2/D_CUR: J914.3, R903.2
/IO/IO2/D_S1: J901.3, R904.1
/IO/IO2/D_S2: J902.3, R905.1
/IO/IO2/D_S3: J903.3, R906.1
/IO/IO2/D_S4: J904.3, R907.1
/IO/IO2/D_S5: J905.3, R908.1
/IO/IO2/D_S6: J906.3, R909.1
/IO/IO2/D_S7: J907.3, R910.1
/IO/IO2/D_S8: J908.3, R911.1
/IO/IO2/D_S9: J909.3, R912.1
/IO/IO2/D_S10: J910.3, R913.1
/IO/IO2/D_S11: J911.3, R914.1
/IO/IO2/D_S12: J912.3, R915.1
/IO/IO2/P_VBUS: C901.1, C902.1, D901.2 (A), J913.A4_B9 (VBUS), J913.B4_A9 (VBUS__1), U901.5 (VBUS)
/IO/IO2/USB_DN: J913.A7 (D-_A), J913.B7 (D-_B), U901.1 (I/O1)
/IO/IO2/USB_DP: J913.A6 (D+_A), J913.B6 (D+_B), U901.3 (I/O2)
/IO/P_LDOIN: D901.1 (K); also elsewhere on the board
/IO/USB_D+: U901.4 (I/O2); also elsewhere on the board
/IO/USB_D-: U901.6 (I/O1); also elsewhere on the board
GND: C901.2, C902.2, C903.2, C904.2, J901.1, J902.1, J903.1, J904.1, J905.1, J906.1, J907.1, J908.1, J909.1, J910.1, J911.1, J912.1, J913.A1_B12 (GND), J913.B1_A12 (GND__1), J914.2, J914.4, J914.MP (MountPin), R901.2, R902.2, U901.2 (GND); also elsewhere on the board

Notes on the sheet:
MOTOR OUT
G 5V S
USB-C Receptacle
Current input voltage: 3V3 max Cut off freq: 159 Hz Place away from switching circuits
(9) IO2
CURRENT SENSOR
Silk Screen Text Pin 1 (left) to 3 (right)
Connector Placement for "motor out" group starting from J901 (top) to J912 (bottom)

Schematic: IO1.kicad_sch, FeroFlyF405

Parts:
C801, C802, C803, C804, C805: 2.2uF; C_0805_2012Metric_Pad1.18x1.45mm_HandSolder; MPN GCM21BR71C225KA64L
J801, J805: SM06B-GHS-TB(LF)(SN); JST_GH_SM06B-GHS-TB_1x06-1MP_P1.25mm_Horizontal; MPN JST_GH_SM06B-GHS-TB
J802, J803, J804: SM04B-GHS-TB(LF)(SN); JST_GH_SM04B-GHS-TB_1x04-1MP_P1.25mm_Horizontal; MPN SM04B-GHS-TB(LF)(SN)
R801, R802: 330; R_0603_1608Metric_Pad0.98x0.95mm_HandSolder; MPN CR0603-FX-3300ELF
TP801, TP802, TP803, TP804, TP805, TP806, TP807: TestPoint; TestPoint_Pad_D1.0mm

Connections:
+5V: C801.1, C802.1, C803.1, C804.1, C805.1, J801.1, J802.1, J803.1, J804.1, J805.1; also elsewhere on the board
/IO/D_I2C1_SCL: J801.4, J803.2; also elsewhere on the board
/IO/D_I2C1_SDA: J801.5, J803.3; also elsewhere on the board
/IO/D_PINIO0: R801.2; also elsewhere on the board
/IO/D_PINIO1: R802.2; also elsewhere on the board
/IO/D_USART2_RX: J805.3, TP806.1 (1_1); also elsewhere on the board
/IO/D_USART2_TX: J805.2, TP805.1 (1_1); also elsewhere on the board
/IO/D_USART4_RX: J802.3; also elsewhere on the board
/IO/D_USART4_TX: J802.2; also elsewhere on the board
/IO/D_USART5_RX: J801.3; also elsewhere on the board
/IO/D_USART5_TX: J801.2; also elsewhere on the board
/IO/IO1/D_PINIO0R: J804.2, R801.1
/IO/IO1/D_PINIO1R: J804.3, R802.1
GND: C801.2, C802.2, C803.2, C804.2, C805.2, J801.6, J801.MP (MountPin), J802.4, J802.MP (MountPin), J803.4, J803.MP (MountPin), J804.4, J804.MP (MountPin), J805.6, J805.MP (MountPin), TP801.1 (1_1), TP802.1 (1_1), TP803.1 (1_1), TP804.1 (1_1), TP807.1 (1_1); also elsewhere on the board

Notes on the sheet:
Telemetry Port
I2C1 Port
PINIO
RC Receiver
(8) IO1
GPS Port
SILK SCREEN TEXT GUIDELINE

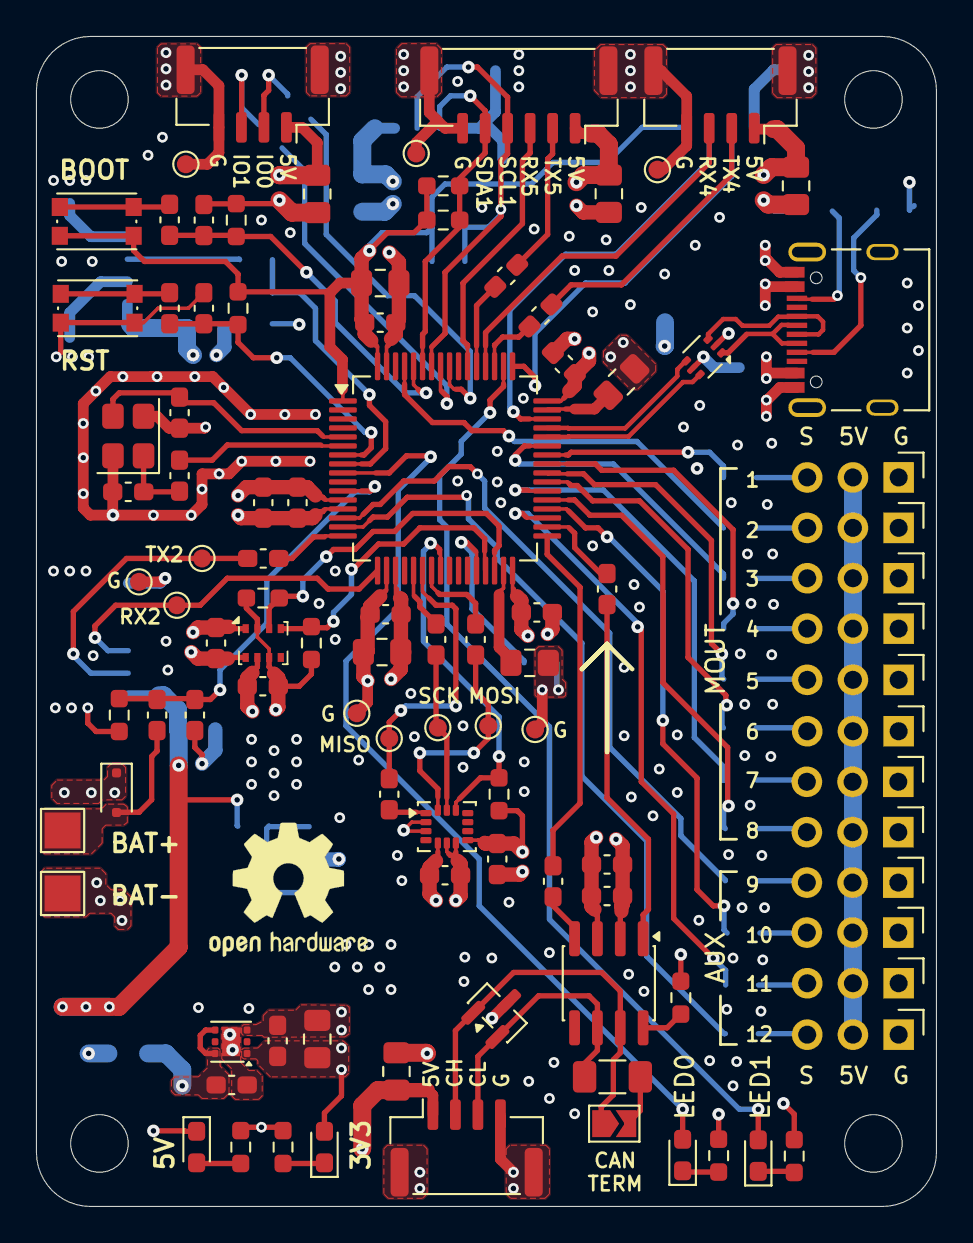
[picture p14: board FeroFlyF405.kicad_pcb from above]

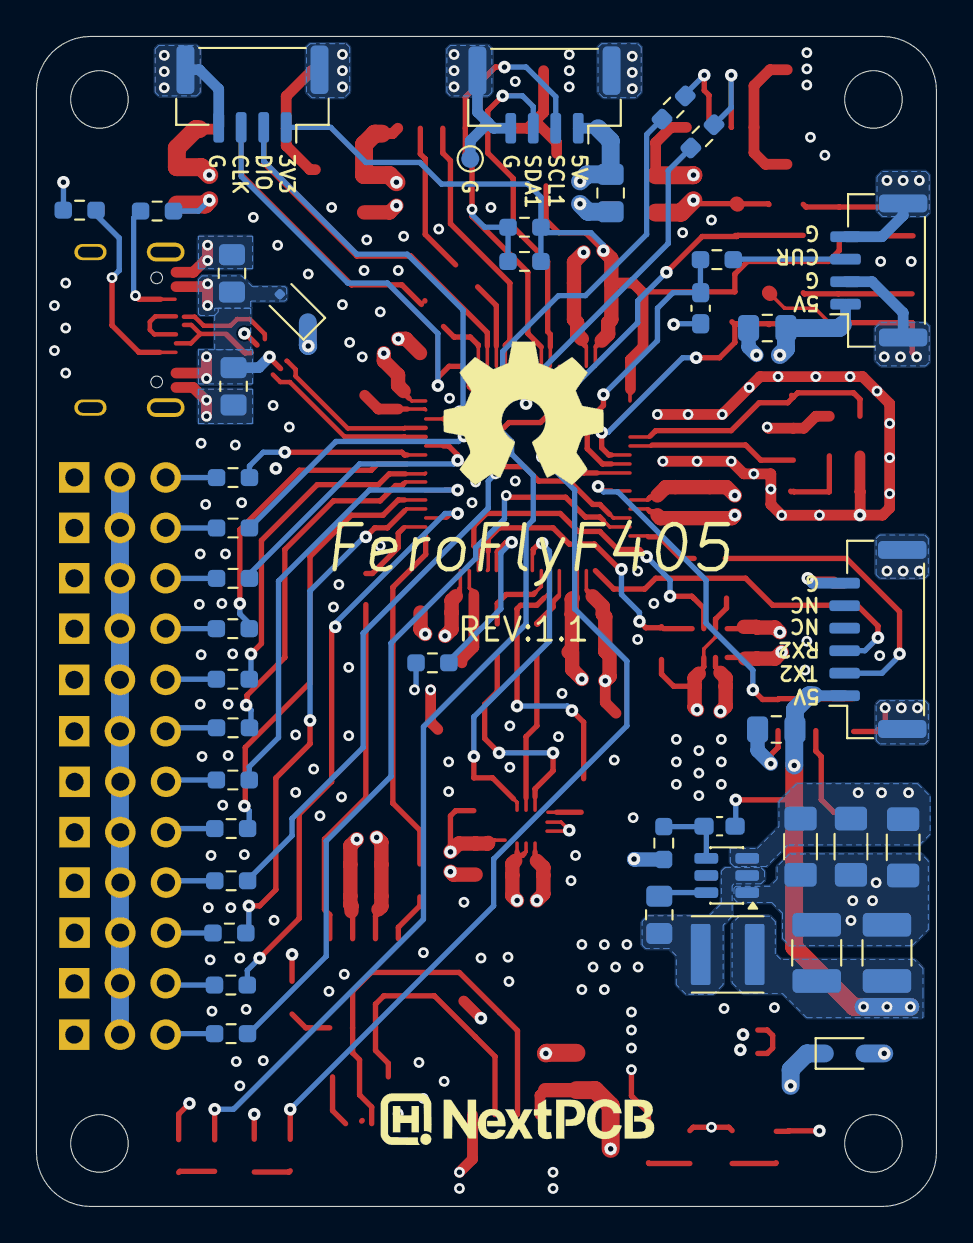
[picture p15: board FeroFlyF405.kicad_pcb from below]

Board: 4 copper layers, 50.0 x 65.0 mm, 147 parts (43 on the bottom side), 93 nets.

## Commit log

2026-07-27 chore: initial commit
    [FeroFly.kicad_pcb, FeroFly.kicad_sch, IMUs.kicad_sch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]
2026-07-27 docs: add author & repo link
    [FeroFly.kicad_sch, IMUs.kicad_sch, IO.kicad_sch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]
2026-07-27 feat: add mounting holes
    [FeroFly.kicad_pcb, FeroFly.kicad_sch]
2026-07-27 feat: add layout notes and net labels
    [FeroFly.kicad_pcb, IMUs.kicad_sch, IO2.kicad_sch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]
2026-07-27 docs: add layout requirement file
    [Layout-requirements-template.xlsx]
2026-08-01 refactor: change name from FeroFly405 to FeroFlyF405
    [FeroFlyF405.kicad_pcb, FeroFlyF405.kicad_sch, IMUs.kicad_sch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]
2026-08-04 refactor(hw): replace BMP390 barometer with DPS368
    [IMUs.kicad_sch]
2026-08-06 refactor(schematic): assign net classes and fix USB net label assingment
    [FeroFlyF405.kicad_sch, IMUs.kicad_sch, MCU.kicad_sch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]
2026-08-08 fix: RSD CAN connection
    [peripherals 2.kicad_sch]
2026-08-08 feat: add intial PCB design & modify pin header lib
    [FeroFlyF405.kicad_pcb]
2026-08-14 fix: change footprint for IO & LDO
    [Power.kicad_sch, peripherals 2.kicad_sch]
2026-08-14 fix: CAN ESD diode connection
    [IO2.kicad_sch]
2026-08-14 chore: initial PCB layout
    [FeroFlyF405.kicad_pcb]
2026-08-16 refactor: change motor output, renamed power nets
    [FeroFlyF405.kicad_sch, IMUs.kicad_sch, IO.kicad_sch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]
2026-08-16 feat: more routing & add design rule clearance exclusion for IMU
    [FeroFlyF405.kicad_pcb]
2026-08-17 feat: change SWD connector, route SWD signal & LEDs
    [FeroFlyF405.kicad_pcb, MCU.kicad_sch]
2026-08-17 refactor: replace 5V power trace with plane & reposition P_LDOIN trace
    [FeroFlyF405.kicad_pcb]
2026-08-17 feat: add stiching vias & silkscreen
    [FeroFlyF405.kicad_pcb]
2026-08-17 feat: add remaing silkscreen & Logos
    [FeroFlyF405.kicad_pcb]
2026-08-18 refactor: rename net
    [peripherals 2.kicad_sch]
2026-08-18 refactor: add & tweak silkscreen
    [FeroFlyF405.kicad_pcb]
2026-08-18 fix: silkcreen name guide and remove excess test points
    [IMUs.kicad_sch, IO1.kicad_sch, IO2.kicad_sch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]
2026-08-18 feat: add last test point & perform final check
    [FeroFlyF405.kicad_pcb]
2026-08-18 feat: add gerbers
    [FeroFlyF405-B_Cu.gbl, FeroFlyF405-B_Mask.gbs, FeroFlyF405-B_Paste.gbp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]
2026-08-18 docs: add board image
2026-08-18 docs: add board pic
2026-08-19 docs: add bom, github and license info
    [FeroFlyF405.kicad_pcb, FeroFlyF405.kicad_sch, IMUs.kicad_sch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]
2026-08-19 feat: add silkscreen & board characteristics and update gerbers
    [FeroFlyF405-B_Cu.gbl, FeroFlyF405-B_Mask.gbs, FeroFlyF405-B_Paste.gbp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]
2026-08-20 docs: remove layout requirements sheet
    [Layout-requirements-template.xlsx]
2026-08-20 feat: add series resistor for PINIO
    [FeroFlyF405-B_Cu.gbl, FeroFlyF405-B_Mask.gbs, FeroFlyF405-B_Paste.gbp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]
2026-08-25 feat: add 3d model for inductor and export board 3d model
    [FeroFlyF405.kicad_pcb, FeroFlyF405.step]
2026-09-04 docs: update step file with silkscreen and pads
    [FeroFlyF405.step]
2026-09-29 refactor: change tim5 ch 1 label to ch 2
    [FeroFlyF405.kicad_sch, IMUs.kicad_sch, IO.kicad_sch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]
2026-09-29 feat: add enclosure
    [FeroFlyF405 Enclosure-Bottom.stl, FeroFlyF405 Enclosure-Led Cap.stl, FeroFlyF405 Enclosure-Top.stl]
2026-10-04 docs: add assembly and printing guide for enclousre
2026-10-05 fix!: change ouput 3 timer from tim4 ch4 to tim1 ch3
    tim4 ch4 does not have dma. Therefore replaced it with tim1 ch3.
    [FeroFlyF405-B_Cu.gbl, FeroFlyF405-B_Mask.gbs, FeroFlyF405-B_Paste.gbp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]
2026-11-03 feat!: add SD Card con, SBUS input & update timer output

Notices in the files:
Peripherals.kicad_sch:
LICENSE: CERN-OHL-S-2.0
